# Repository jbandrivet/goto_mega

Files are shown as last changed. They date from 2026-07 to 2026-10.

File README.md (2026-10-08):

# GotoAndrivet — Contrôleur Multi-Montures OnStep

Ce projet supporte de manière universelle trois types de montures astronomiques :
1. **Alt-Azimutale (AltAz)** : Pour montures Dobson et Alt-Azimutales standards.
2. **Fourche Équatoriale (ForkEq)** : Pour montures équatoriales à fourche ou tables équatoriales (aucun retournement de méridien requis, suivi sidéral direct sur l'angle horaire).
3. **Monture Équatoriale Allemande (GermanEq / GEM)** : Pour montures équatoriales allemandes (gestion automatique du **retournement de méridien** et de la position de pilier *Pier Side* Est/Ouest).

---

## Structure du Projet

* **`goto_andrivet.py`** : L'application principale en Python (interface graphique Tkinter avec carte du ciel interactive, catalogues Messier/NGC/IC/Caldwell et dérotateur).
* **`goto_andrivet_config_tool.py`** : L'utilitaire de configuration en style Windows 95 permettant de régler les coordonnées, vitesses, rapports d'engrenage et de flasher le firmware.
* **`raquette_virtuelle.py`** : L'émulateur de la raquette Teensy pour piloter le télescope depuis l'ordinateur.
* **`mega_monture/`** : Le firmware classique (1 étoile) pour le contrôleur Arduino Mega 2560.
* **`teensy_monture/`** : Le nouveau firmware haute performance pour contrôleur Teensy 4.1 (Inclut le Modèle de Pointage N-Étoiles par interpolation IDW).
* **`teensy_raquette/`** : Le firmware C++ pour la raquette physique avec écran LCD (sur Teensy 4.1).

---

## Guide d'Installation & Mode d'Emploi

### 1. Prérequis
Pour exécuter les applications graphiques en Python sur votre ordinateur, vous devez disposer de **Python 3**, du module **Tkinter** et de la bibliothèque **pyserial**.

Sur Ubuntu / Debian / Raspberry Pi OS, installez-les via votre terminal :
```bash
sudo apt update
sudo apt install python3 python3-tk python3-pip
pip3 install pyserial
```

### 2. Démarrage des Applications
Exécutez les scripts Python correspondants depuis le dossier du projet :

* **Configuration & Flashage** :
  ```bash
  python3 goto_andrivet_config_tool.py
  ```
* **Cartographie du Ciel & Pilotage** :
  ```bash
  python3 goto_andrivet.py
  ```
* **Raquette Virtuelle (Émulateur)** :
  ```bash
  python3 raquette_virtuelle.py
  ```

### 3. Compiler & Flasher sans IDE Arduino
Vous pouvez programmer vos cartes directement depuis l'utilitaire de configuration (sans avoir besoin d'ouvrir l'IDE Arduino classique) :
1. Installez l'utilitaire [arduino-cli](https://arduino.github.io/arduino-cli/latest/) sur votre PC.
2. Ouvrez l'utilitaire de configuration (`python3 goto_andrivet_config_tool.py`).
3. Sélectionnez le **Port** série de votre carte dans les paramètres de connexion.
4. Dans l'encadré **« Téléversement du Firmware »**, cliquez sur le bouton correspondant à votre carte pour compiler et flasher automatiquement.

### 4. Schéma de Câblage Rapide (Monture : Mega ou Teensy)

Câblez votre contrôleur principal en suivant ce schéma (les broches sont identiques pour le Mega et le Teensy, à l'exception de la broche du Buzzer) :

| Composant / Axe | Broche Arduino Mega 2560 | Broche Teensy 4.1 | Signal Module / Driver |
| :--- | :--- | :--- | :--- |
| **Moteur Azimut (AZ/RA)** | **Pin 2** | **Pin 2** | `PUL+` (Pulse/Step) |
| | **Pin 3** | **Pin 3** | `DIR+` (Direction) |
| | **Pin 4** | **Pin 4** | `ENB+` (Enable) |
| **Moteur Altitude (ALT/DEC)** | **Pin 5** | **Pin 5** | `PUL+` (Pulse/Step) |
| | **Pin 6** | **Pin 6** | `DIR+` (Direction) |
| | **Pin 7** | **Pin 7** | `ENB+` (Enable) |
| **Moteur Dérotateur** | **Pin 8** | **Pin 8** | `PUL+` (Pulse/Step) |
| | **Pin 9** | **Pin 9** | `DIR+` (Direction) |
| | **Pin 10** | **Pin 10** | `ENB+` (Enable) |
| **Moteur Focuseur** | **Pin 11** | **Pin 11** | `PUL+` (Pulse/Step) |
| | **Pin 12** | **Pin 12** | `DIR+` (Direction) |
| | **Pin 13** | **Pin 21** | `ENB+` (Enable) |
| **Buzzer** | **Pin 49** | **Pin 20** | Borne `+` (actif : direct / passif : via résistance 100 Ω) |
| **Port Série PC** | **Non dispo** | **Pin 25 (RX6)** | `TX` de l'adaptateur USB/Série TTL (Câble long) |
| | **Non dispo** | **Pin 24 (TX6)** | `RX` de l'adaptateur USB/Série TTL |
| **Raquette Teensy** | **Pin 15 (RX3)** | **Pin 15 (RX3)** | `TX` de la raquette Teensy |
| | **Pin 14 (TX3)** | **Pin 14 (TX3)** | `RX` de la raquette Teensy |
| **Module GPS** | **Pin 17 (RX2)** | **Pin 17 (RX4)** | `TX` du module GPS |
| | **Pin 16 (TX2)** | **Pin 16 (TX4)** | `RX` du module GPS |

*Note : Les signaux de masse négatifs (`PUL-`, `DIR-`, `ENB-` des drivers, GND du buzzer, du GPS et de la Teensy) doivent tous être connectés à une broche **GND** de votre carte.*
*(Consultez le fichier `fiche_technique.md` pour des explications approfondies).*

### 4.1 Schéma de Câblage de la Raquette (Teensy 4.1)

Si vous fabriquez la raquette physique avec un Teensy 4.1, voici le câblage à effectuer :

| Composant | Broche Teensy 4.1 | Connexion / Signal |
| :--- | :--- | :--- |
| **Écran LCD (I2C)** | **Pin 18 (SDA0)** | `SDA` de l'écran LCD |
| | **Pin 19 (SCL0)** | `SCL` de l'écran LCD |
| | **VIN** | `VCC` (5V) de l'écran LCD |
| | **GND** | `GND` de l'écran LCD |
| **Boutons Poussoirs** | **Pin 6** | Bouton **Haut (UP)** (vers GND) |
| | **Pin 7** | Bouton **Bas (DOWN)** (vers GND) |
| | **Pin 8** | Bouton **Gauche (LEFT)** (vers GND) |
| | **Pin 9** | Bouton **Droite (RIGHT)** (vers GND) |
| | **Pin 10** | Bouton **Validation (ENTER)** (vers GND) |
| **Câble RJ11 (vers Mega)**| **GND** | Pin 1 RJ11 (`GND` de la Monture) |
| | **VIN** | Pin 2 RJ11 (`VIN` / `5V` de la Monture) |
| | **Pin 1 (TX1)** | Pin 3 RJ11 (vers `RX3` Pin 15 Monture) |
| | **Pin 0 (RX1)** | Pin 4 RJ11 (vers `TX3` Pin 14 Monture) |

*ATTENTION : Le Teensy est alimenté par la pin 5V du Mega via VIN. Ne pas brancher l'USB du Teensy en même temps, sauf si le pad VUSB a été coupé au préalable.*

### 5. Arduino Mega 2560 vs Teensy 4.1 (Contrôleur de Monture)

Le projet vous permet de choisir le cerveau principal de la monture. Bien que le câblage soit quasiment identique, voici les différences pour vous aider à choisir :

| Caractéristique | Arduino Mega 2560 | Teensy 4.1 |
| :--- | :--- | :--- |
| **Vitesse de calcul** | 16 MHz (8-bit) | **600 MHz** (32-bit ARM) |
| **Précision (Maths)** | Flottants 32-bit lents | **Flottants 64-bit (double)** natifs ultra-rapides |
| **Microstepping & Vitesse max**| Limité (saturera à très haut microstepping) | **Parfait** (génère des impulsions à plus de 200kHz sans sourciller) |
| **Modèle de pointage** | Basique | **N-Étoiles** (50 points mémorisés avec calculs IDW) |
| **Evolutivité (Futur)** | Faible | **Très haute** (Port USB Host pour Manette/Gamepad) |
| **Coût** | ~15-20€ (Clones pas chers) | ~35-40€ |

**Recommandation** : Si vous utilisez de petits drivers (1/16 ou 1/32 de pas) et voulez un système économique, le **Mega 2560** fait parfaitement le travail. Si vous utilisez des drivers modernes (TMC2209, M542) à fort microstepping (1/128, 1/256), que vous voulez des déplacements GoTo ultra-rapides et silencieux, et le modèle de pointage multi-étoiles intégré, optez sans hésiter pour le **Teensy 4.1**.

### 6. Matériel Compatible

Pour monter votre système GotoAndrivet, les composants matériels suivants sont compatibles et recommandés :

* **Cartes de Contrôle** :
  * **Arduino Mega 2560** ou **Teensy 4.1** (au choix pour la carte principale de la monture).
  * **Teensy 4.1** (pour la raquette de commande physique - *Optionnelle*).
* **Drivers de Moteurs** :
  * Drivers standard acceptant des entrées `PUL/DIR` (Impulsion/Direction) comme les modèles **M542**, **DM542**, **TB6600**, **TMC2209**, etc.
* **Moteurs** :
  * Moteurs pas à pas bipolaires (ex. **NEMA 17** ou **NEMA 23** en 200 pas/tour).
* **Module GPS (Optionnel)** :
  * Module **Adafruit Ultimate GPS** (MTK3339) ou tout autre récepteur GPS délivrant des trames NMEA standards à 9600 bauds sur port série.
* **Afficheur Raquette** :
  * Écran **LCD 20x4** caractères équipé d'un adaptateur **I2C** (généralement à l'adresse `0x27`).
* **Boutons Raquette** :
  * 5 boutons poussoirs momentanés (Haut, Bas, Gauche, Droite, Validation).
* **Alerte Sonore** :
  * Un **Buzzer actif 5V** ou un **Buzzer passif**. (Si vous utilisez un buzzer actif, câblez-le directement ; si vous utilisez un buzzer passif, ajoutez une résistance de 100 Ω en série avec le signal).

*Note concernant la raquette physique : La construction de la raquette matérielle (carte Teensy, écran LCD et boutons) n'est **pas obligatoire**. Si vous utilisez la monture en mode "remote", ou que vous la pilotez exclusivement depuis un PC, un planétarium, ou un boîtier type ASIAIR, l'Arduino Mega suffit à lui seul pour tout gérer via la connexion USB.*

---

## Fonctionnalités Avancées

* **Modèle de Pointage N-Étoiles (Teensy Monture uniquement)** : Interpolation des erreurs de suivi et de pointage par IDW (Inverse Distance Weighting) jusqu'à 50 étoiles mémorisées. Support de la commande de remise à zéro `:CML#`.
* **Ajout du type de monture `GermanEq`** : Le firmware de l'Arduino Mega calcule automatiquement les inversions d'axes (Ascension Droite et Déclinaison) lors du franchissement du méridien.
* **Commande standard `:Gm#` implémentée** : Renvoie le *Pier Side* (`E#` pour l'Est, `W#` pour l'Ouest, `N#` pour les autres modes) requis pour les logiciels de guidage comme Ekos/INDI.
* **Commande standard `:D#` implémentée** : Permet l'interrogation dynamique du statut de pointage (Slewing), accélérant drastiquement le modèle de pointage automatique ZWO en évitant les pauses fixes.
* **Intégration complète dans les interfaces** : Le sélecteur de monture dans `goto_andrivet_config_tool.py`, `goto_andrivet.py` et la raquette physique Teensy supporte désormais les trois options distinctes (`AltAz`, `ForkEq`, `GermanEq`).

---

## Licence

Ce projet est sous licence **GNU GPL v3**. Consultez le fichier [LICENSE](LICENSE) pour plus de détails.

## Mise à jour Matérielle (PCB 36V / 12V + Drivers Externes)
- Ajout du support matériel et logiciel (SPI) pour les drivers Pololu 36v8 et StepSticks TMC5160 HV.
- La carte mère dispose désormais de connecteurs universels (StepSticks + sorties pour drivers externes 4 pins).
- Suppression du port USB Host redondant sur le Teensy 4.1 de la monture pour simplifier le soudage.
- Ajout d'une prise Jack 12V standard en parallèle du bornier d'alimentation 36V.
- Le configurateur PC intègre maintenant une case à cocher pour activer dynamiquement le SPI matériel pour les drivers haute puissance.

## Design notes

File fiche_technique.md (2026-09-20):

# FICHE TECHNIQUE : SYSTÈME DE COMMANDE GOTO-ANDRIVET
*Version 9.2 (Dual Architecture : Mega & Teensy) — Juin 2026*

Ce document regroupe les spécifications électriques, le schéma de câblage des drivers **M542**, les paramètres mécaniques et les protocoles de communication pour le système de commande motorisé GoTo universel (GotoAndrivet).

---

## 1. Choix de l'Architecture (Monture Mega vs Teensy)

Le projet **Goto-Andrivet** propose désormais deux versions différentes pour le "cerveau" de la monture (le contrôleur moteur principal). Le choix de la carte affecte directement la puissance de calcul pour le suivi et les modèles de pointage.

### Option A : Contrôleur Arduino Mega 2560 (Dossier `mega_monture`)
* **Processeur :** 8-bit AVR @ 16 MHz.
* **Avantage :** Matériel très standard, robuste et peu cher.
* **Inconvénient :** Puissance de calcul très limitée. Il effectue d'excellents suivis basiques (1 étoile), mais il est incapable de faire fonctionner des modèles de pointage complexes (multi-étoiles) sans perdre la fluidité des moteurs.

### Option B : Contrôleur Teensy 4.1 (Dossier `teensy_monture`)
* **Processeur :** 32-bit ARM Cortex-M7 @ 600 MHz avec coprocesseur mathématique (FPU).
* **Avantage :** Une puissance phénoménale. Il génère des pas moteurs d'une fluidité parfaite même à très haute vitesse et permet les calculs matriciels complexes requis pour l'alignement multi-étoiles sans aucune saccade.
* **Inconvénient :** Plus coûteux.

> [!NOTE]
> Quel que soit le contrôleur choisi pour la monture, la télécommande (**Raquette**) reste toujours propulsée par un Teensy 4.1 (Dossier `teensy_raquette`) en raison de l'affichage graphique LCD et des calculs d'éphémérides requis.

---

## 2. Caractéristiques de Communication

*   **Liaison USB (PC / ASIAir / INDI) :** **38 400 bauds** (Vitesse optimisée pour la télémétrie en temps réel).
*   **Liaison Série PC (Connecteur PCB 4 broches / Serial6) :** **38 400 bauds** (Idéal pour câbles très longs avec adaptateur TTL/RS485).
*   **Liaison Raquette (Connecteur DIN 4 broches / Serial3) :** **38 400 bauds**.
*   **Protocole :** Meade LX200 avec extensions OnStep (supporté par KStars/Ekos, Stellarium, SkySafari).

---

## 3. Schéma de Câblage Électrique (Côté Monture)

Le câblage des drivers moteurs vers le contrôleur reste quasiment identique quelle que soit la carte utilisée. Les drivers M542 sont raccordés en configuration **Cathode Commune (GND commun)**.

### Broches selon le contrôleur choisi :

| Composant | Broche Arduino Mega 2560 | Broche Teensy 4.1 |
|---|---|---|
| **Moteur AZ (Step)** | Pin 2 | Pin 2 |
| **Moteur AZ (Dir)** | Pin 3 | Pin 3 |
| **Moteur ALT (Step)** | Pin 5 | Pin 5 |
| **Moteur ALT (Dir)** | Pin 6 | Pin 6 |
| **Buzzer (Actif ou Passif)** | Pin 49 | Pin 20 |
| **GPS (RX / TX)** | Pin 17 / Pin 16 (Serial2) | Pin 16 / Pin 17 (Serial4) |
| **Raquette (RX / TX)** | Pin 15 / Pin 14 (Serial3) | Pin 15 / Pin 14 (Serial3) |

> [!IMPORTANT]
> Pour le Teensy 4.1, les broches physiques pour le GPS restent aux emplacements 16 et 17, mais elles correspondent au port matériel `Serial4` (au lieu du `Serial2` sur le Mega). Le câblage physique des fils volants est donc préservé !

---

## 4. Paramètres Mécaniques et Résolutions

La résolution de déplacement (PPD - Pas par Degré) de la monture est calculée selon la formule :

$$PPD = \frac{\text{Pas Moteur} \times \text{Microstepping} \times \text{Rapport Réduction}}{360}$$

### Valeurs (À configurer par l'utilisateur) :
*   **Pas moteur par tour :** Généralement 200 pas (pour des moteurs 1.8°).
*   **Microstepping :** À configurer selon votre driver (ex: 16, 32, 64, 128).
*   **Rapport de réduction (AZ/ALT) :** Défini par l'utilisateur (à configurer impérativement via l'utilitaire selon votre mécanique propre).
*   **Résolution calculée (PPD) :** Calculée automatiquement par l'utilitaire en fonction des trois valeurs ci-dessus.

---

## 5. Modes de Suivi (Tracking)

*   **Suivi Sidéral (Ciel profond) :** Calculé en temps réel toutes les 500 ms à partir du Temps Sidéral Local (LST) de l'horloge.
*   **Suivi Lunaire (`:TL#`) :** Vitesse de l'angle horaire (HA) ralentie de **~2,37%** (facteur d'échelle `0.976327`) pour compenser le déplacement orbital de la Lune.
*   **Suivi Solaire (`:TS#`) :** Vitesse ralentie de **~0,27%** (facteur d'échelle `0.997270`) pour compenser le mouvement orbital de la Terre.

---

## 6. Câblage de la Raquette Physique (Teensy 4.1)

La raquette physique est articulée autour d'une carte **Teensy 4.1**.

### 1. Connecteur DIN 4 broches (Communication + Alimentation depuis la Monture)

| Pin DIN | Signal | Broche Teensy |
|---|---|---|
| **1** | GND | **GND** |
| **2** | 5V (alimentation) | **VIN** |
| **3** | TX (Teensy → Monture) | **Pin 1 (TX1)** |
| **4** | RX (Monture → Teensy) | **Pin 0 (RX1)** |

> [!WARNING]
> La monture doit fournir assez de courant au Teensy via la pin VIN. Ne pas alimenter le Teensy par son port USB si le câble DIN l'alimente déjà, sauf si le pad `VUSB` sous le Teensy a été physiquement sectionné.

### 2. Écran LCD Grove I2C
* **SDA** $\rightarrow$ Broche **Pin 18 (SDA0)** de la Teensy
* **SCL** $\rightarrow$ Broche **Pin 19 (SCL0)** de la Teensy
* **VCC** $\rightarrow$ Broche **5V** (ou **3.3V** selon le modèle Grove)
* **GND** $\rightarrow$ Broche **GND**

### 3. Boutons Poussoirs (Clavier directionnel)
Les boutons sont câblés en **INPUT_PULLUP** (reliés entre la broche et le GND). Aucun besoin de résistance externe !

* **Haut (UP)** $\rightarrow$ Broche **Pin 6**
* **Bas (DOWN)** $\rightarrow$ Broche **Pin 7**
* **Gauche (LEFT)** $\rightarrow$ Broche **Pin 8**
* **Droite (RIGHT)** $\rightarrow$ Broche **Pin 9**
* **Entrée/OK (ENTER)** $\rightarrow$ Broche **Pin 10**

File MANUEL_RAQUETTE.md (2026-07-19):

# Mode d'emploi : Raquette Teensy

Ce document décrit comment naviguer dans l'interface LCD de la raquette Teensy et détaille l'ensemble des menus disponibles.

## Navigation Générale

L'écran d'accueil affiche les coordonnées de la monture (soit en RA/DEC, soit en ALT/AZ). 

Depuis cet écran d'accueil :
- **Touches directionnelles (Haut, Bas, Gauche, Droite)** : Déplacement manuel des moteurs (vitesse de rattrapage).
- **Touche `ENTRÉE` (ou bouton central)** : Ouvre le Menu Principal.

À l'intérieur des menus :
- **Haut / Bas** : Déplacer le curseur de sélection ou modifier une valeur (par exemple changer un chiffre).
- **Entrée (ou Droite)** : Valider un choix ou entrer dans un sous-menu.
- **Gauche** : Annuler, reculer ou retourner au menu précédent.

## Le Menu Principal

En appuyant sur `Entrée` depuis l'écran d'accueil, vous accédez aux 15 options suivantes :

### 1. Catalogues
Permet d'accéder aux catalogues d'objets célestes (Messier, NGC, IC, Système Solaire, Étoiles remarquables). Sélectionnez un catalogue, puis un objet, et faites Entrée pour lancer le **GoTo** automatique vers cet objet.

### 2. Pause Moteurs / Reprendre Suivi
- **Pause Moteurs** : Coupe le suivi et l'alimentation des moteurs (pratique pour économiser la batterie ou manipuler la monture sans forcer). Le télescope retient sa position interne en fonction du temps qui passe.
- **Reprendre Suivi** : Réactive le suivi. Si vous aviez une cible GoTo active, le télescope va recalculer la position actuelle de la cible et s'y recentrer automatiquement.

### 3. Vitesse GoTo
Permet de brider la vitesse maximale des moteurs lors des grands déplacements (GoTo). Utile si votre alimentation est faible ou pour réduire le bruit (en degrés par seconde).

### 4. Buzzer
Active ou désactive les bips de confirmation de la raquette.

### 5. Synchroniser
Procédure d'alignement. Après avoir lancé un GoTo vers une étoile ou une planète, centrez-la parfaitement à l'aide des touches fléchées puis utilisez cette fonction. L'Arduino va alors se "synchroniser" et considérer que sa position mécanique actuelle correspond exactement à cet objet.

### 6. Parking
Gère la mise au repos de la monture.
- **Parquer** : Envoie le télescope vers sa position de repos sécurisée et coupe le suivi.
- **Déparquer** : Réveille la monture pour une nouvelle session (sans perdre l'alignement).
- **Définir Position** : Enregistre la position *actuelle* comme étant la future position de parking.

### 7. Type Monture
Définit la géométrie de votre monture :
- Alt-Az (Azimutale)
- Equatorial (Fourche ou Allemande)

### 8. Ratio AZ / Ratio RA
Règle la démultiplication mécanique (ratio des poulies/engrenages) de l'axe Azimut (ou Ascension Droite).

### 9. Ratio ALT / Ratio DEC
Règle la démultiplication mécanique de l'axe Altitude (ou Déclinaison).

### 10. Alim Moteurs
Permet d'allumer ou d'éteindre complètement l'étage de puissance des moteurs manuellement.

### 11. Date / Heure
Règle la date et l'heure locale, ainsi que le décalage UTC. *(L'heure est essentielle pour le calcul des positions célestes).*

### 12. Lieu Obs.
Saisie des coordonnées GPS de votre lieu d'observation (Latitude et Longitude).

### 13. Langue
Bascule l'interface de la raquette entre le **Français** et l'**Anglais**.

### 14. GPS Auto
Active ou désactive la synchronisation automatique de l'heure et du lieu grâce au module GPS matériel (si branché).

### 15. Affichage Coord
Permet de choisir ce que l'écran d'accueil affiche en temps réel :
- Coordonnées équatoriales (Ascension Droite et Déclinaison).
- Coordonnées horizontales (Altitude et Azimut).

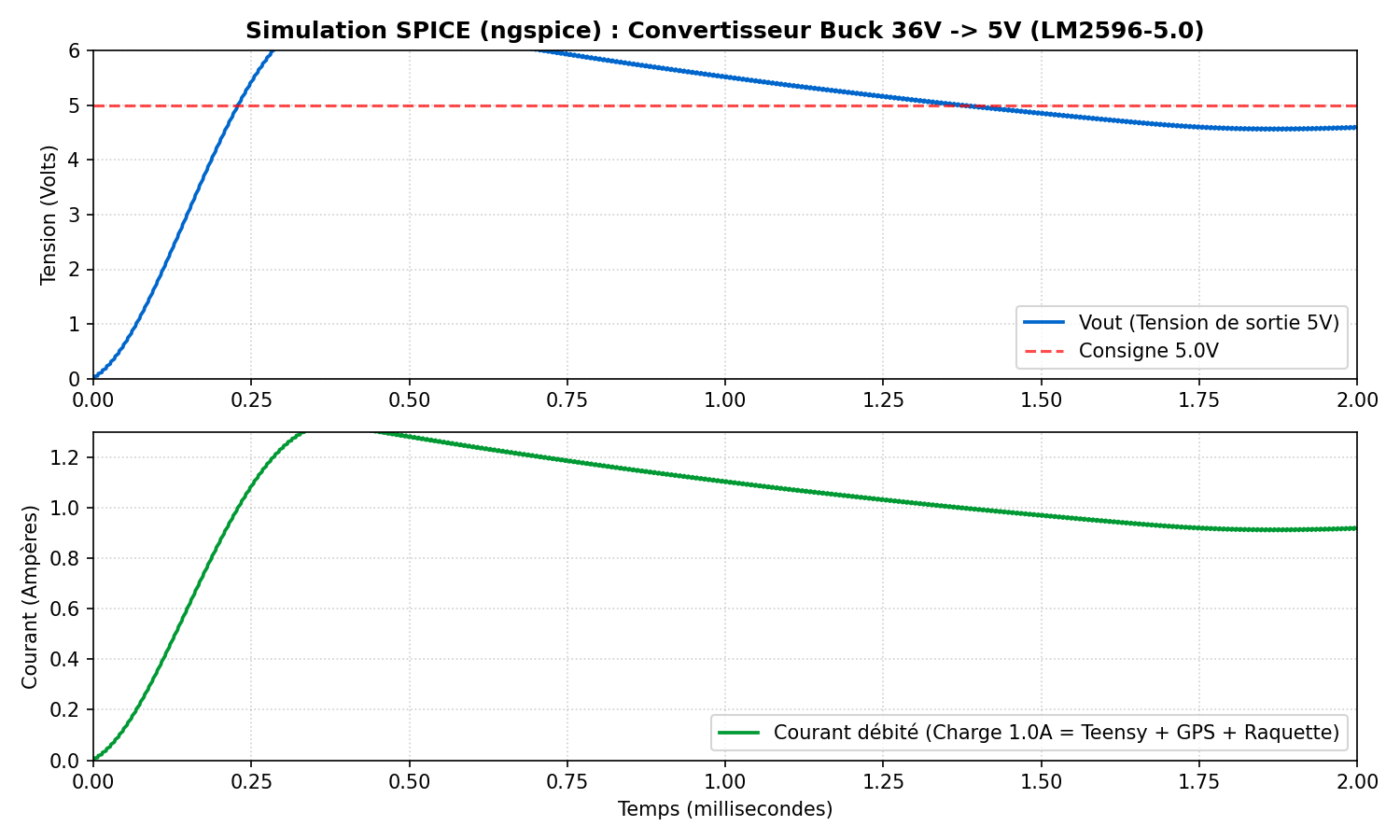
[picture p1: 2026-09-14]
pcb/simulation/simulation_buck_36v_5v.png

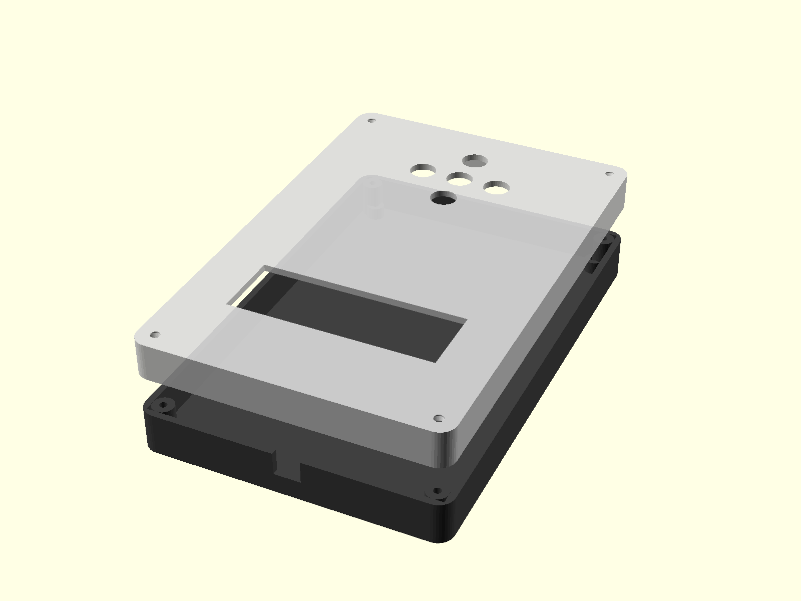
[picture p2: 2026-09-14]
pcb/raquette/boitier_raquette_3d.png

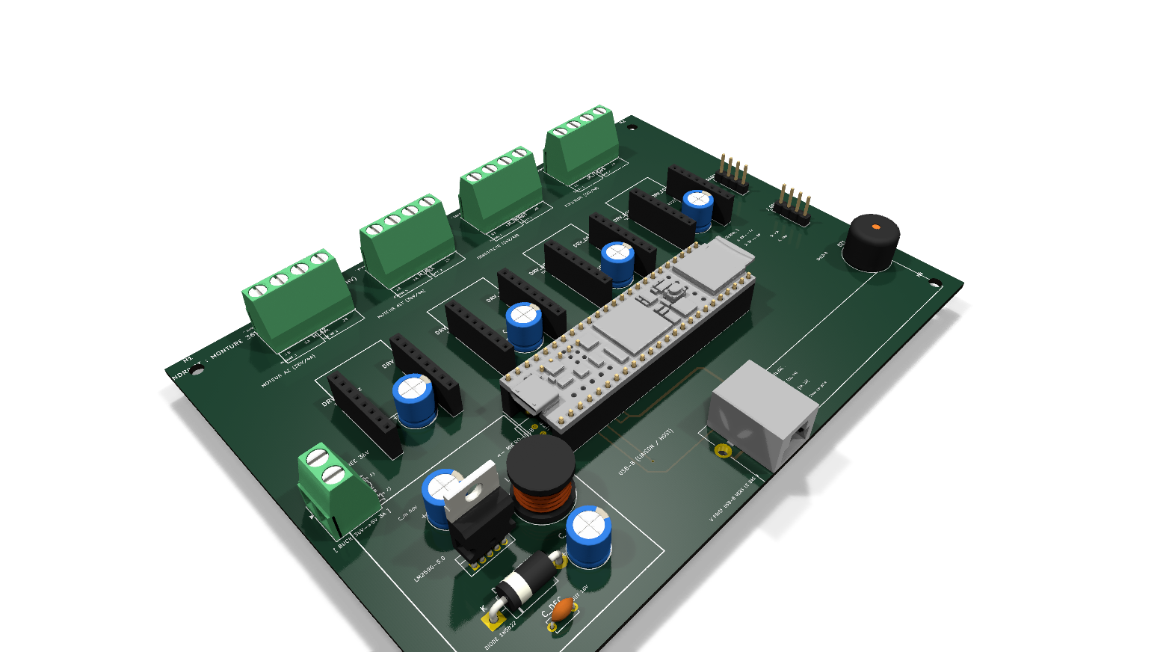
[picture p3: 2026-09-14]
pcb/monture/monture_3d.png

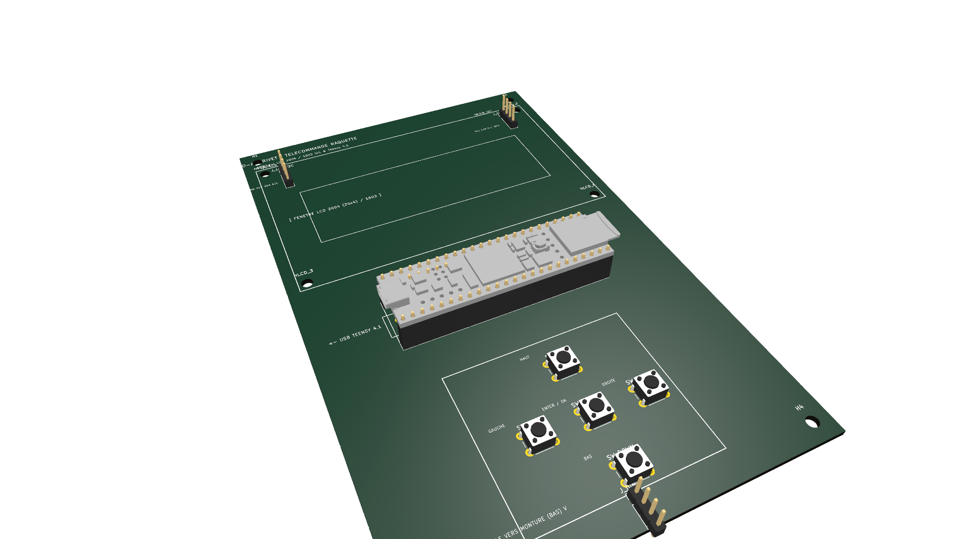
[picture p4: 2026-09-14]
pcb/raquette/raquette_3d.png

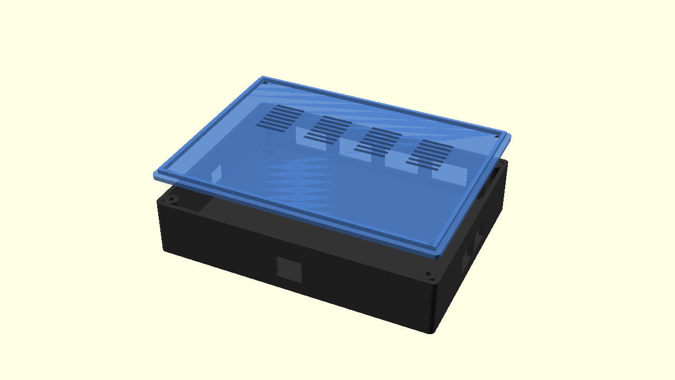
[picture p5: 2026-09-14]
pcb/monture/boitier_monture_3d.png

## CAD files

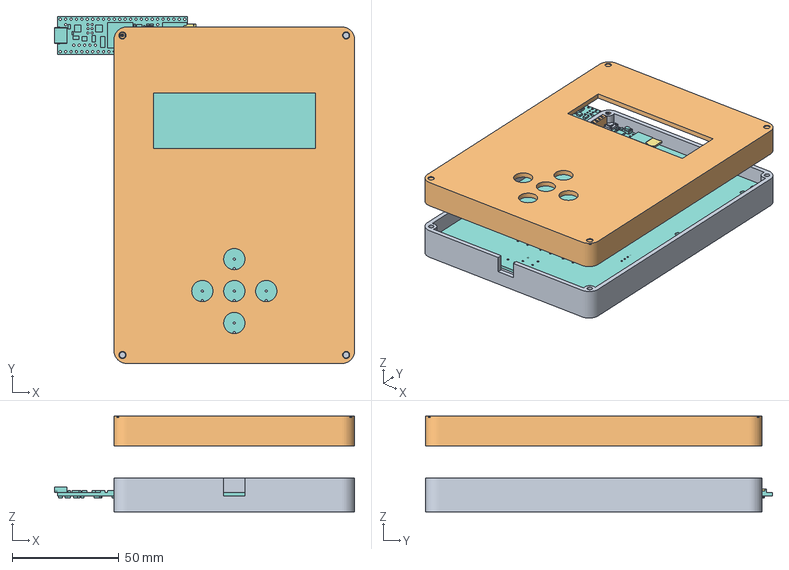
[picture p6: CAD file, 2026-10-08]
pcb/raquette/boitier_raquette_assemblage.FCStd
141.0 x 162.9 x 45.0 mm
PinSocket_1x24_P2.54mm_Vertical
PinSocket_1x24_P2.54mm_Vertical002
PinHeader_1x24_P254mm_Vertical
PinHeader_1x24_P254mm_Vertical001
PinSocket_1x05_P2.54mm_Vertical
PinHeader_1x05_P254mm_Vertical
Teensy_4.1_Assembly_R1
Teensy_4.1_Assembly_R001
SW_PUSH_6mm
SW_PUSH_6mm002
SW_PUSH_6mm004
PinHeader_1x04_P254mm_Vertical
SW_PUSH_6mm006
SW_PUSH_6mm008
PinHeader_1x04_P254mm_Vertical001
raquette_PCB
Boitier_Raquette_Base
Boitier_Raquette_Face_Avant

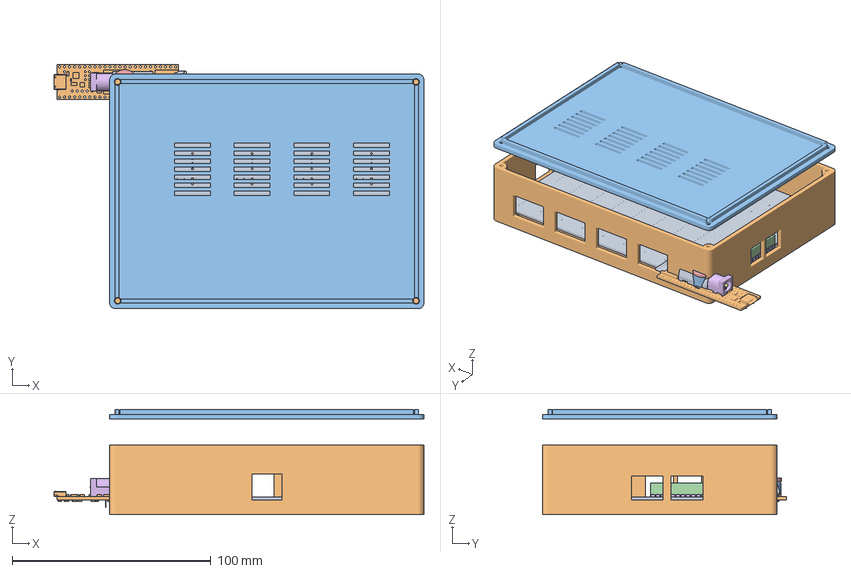
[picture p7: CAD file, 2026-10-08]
pcb/monture/boitier_monture_assemblage.FCStd
186.0 x 122.9 x 53.0 mm
PinHeader_1x04_P254mm_Vertical
D_DO-201AD_P15.24mm_Horizontal
PinSocket_1x08_P2.54mm_Vertical
CP_Radial_D80mm_P350mm
PinHeader_1x04_P254mm_Vertical001
PinSocket_1x08_P2.54mm_Vertical002
CP_Radial_D80mm_P350mm001
TerminalBlock_Phoenix_MKDS_15_4_508_1x04_P508mm_Horizontal
PinSocket_1x08_P2.54mm_Vertical004
C_Disc_D50mm_W25mm_P500mm
TerminalBlock_Phoenix_MKDS_15_4_508_1x04_P508mm_Horizontal001
PinSocket_1x08_P2.54mm_Vertical006
CP_Radial_D80mm_P350mm002
CP_Radial_D80mm_P350mm003
PinSocket_1x08_P2.54mm_Vertical008
PinSocket_1x08_P2.54mm_Vertical010
TerminalBlock_Phoenix_MKDS_15_4_508_1x04_P508mm_Horizontal002
TerminalBlock_Phoenix_MKDS_15_4_508_1x04_P508mm_Horizontal003
PinHeader_1x04_P254mm_Vertical002
CP_Radial_D80mm_P350mm004
TerminalBlock_Phoenix_MKDS_15_2_508_1x02_P508mm_Horizontal
BarrelJack_Horizontal
BarrelJack_Horizontal001
BarrelJack_Horizontal002
BarrelJack_Horizontal003
BarrelJack_Horizontal004
PinSocket_1x24_P2.54mm_Vertical
PinSocket_1x24_P2.54mm_Vertical002
PinHeader_1x24_P254mm_Vertical
PinHeader_1x24_P254mm_Vertical001
PinSocket_1x05_P2.54mm_Vertical
PinHeader_1x05_P254mm_Vertical
Teensy_4.1_Assembly_R1
Teensy_4.1_Assembly_R001
Buzzer_12x95RM76
PinSocket_1x08_P2.54mm_Vertical012
L_Radial_D12.5mm_P7.00mm_Fastron_09HCP
TO_220_5_Pentawatt_Multiwatt_5_Vertical
PinSocket_1x08_P2.54mm_Vertical014
CP_Radial_D80mm_P350mm005
monture_PCB
boitier_monture_base
boitier_monture_couvercle

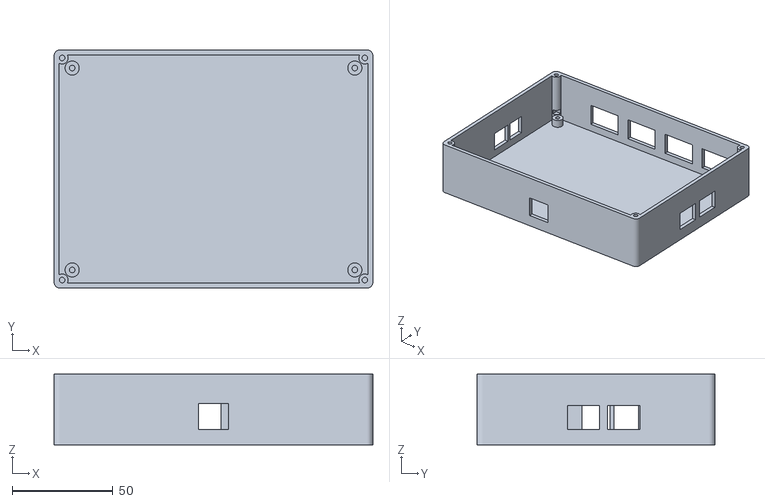
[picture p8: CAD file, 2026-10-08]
pcb/monture/boitier_monture_base.stl
158.0 x 118.0 x 35.0

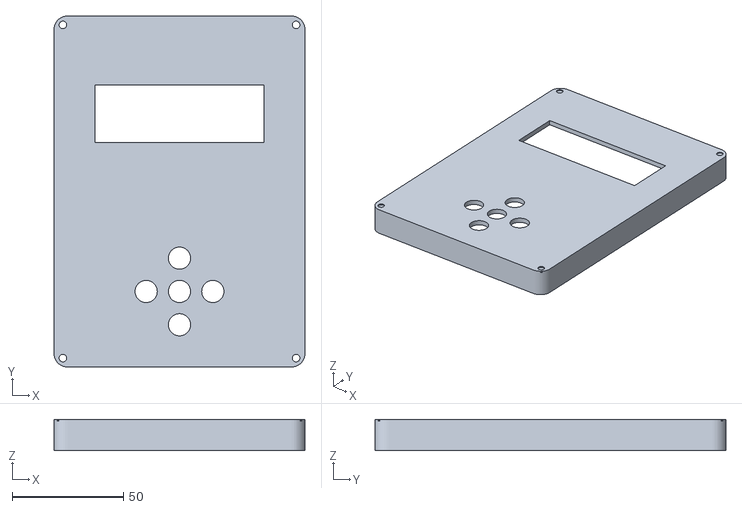
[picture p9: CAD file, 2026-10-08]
pcb/raquette/boitier_raquette_face_avant.stl
113.0 x 158.0 x 14.0

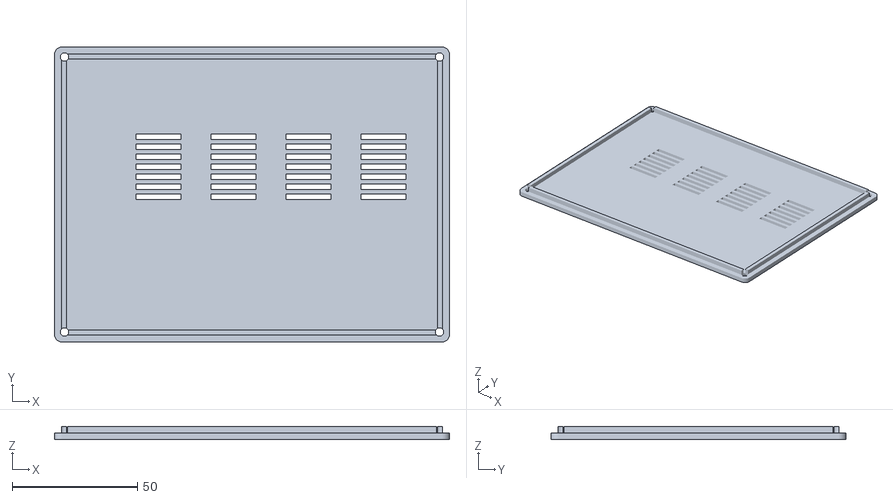
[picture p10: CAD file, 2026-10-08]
pcb/monture/boitier_monture_couvercle.stl
158.0 x 118.0 x 5.00

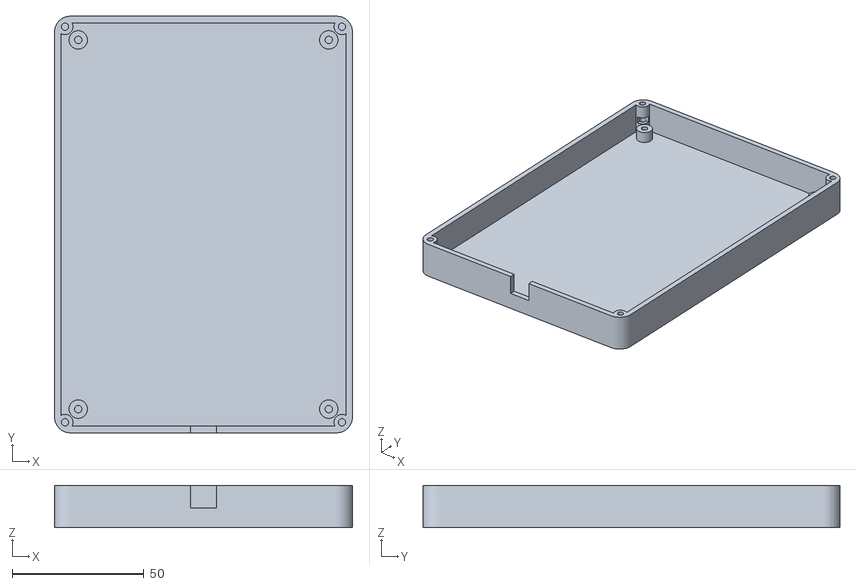
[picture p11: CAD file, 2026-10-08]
pcb/raquette/boitier_raquette_base.stl
113.0 x 158.0 x 16.0

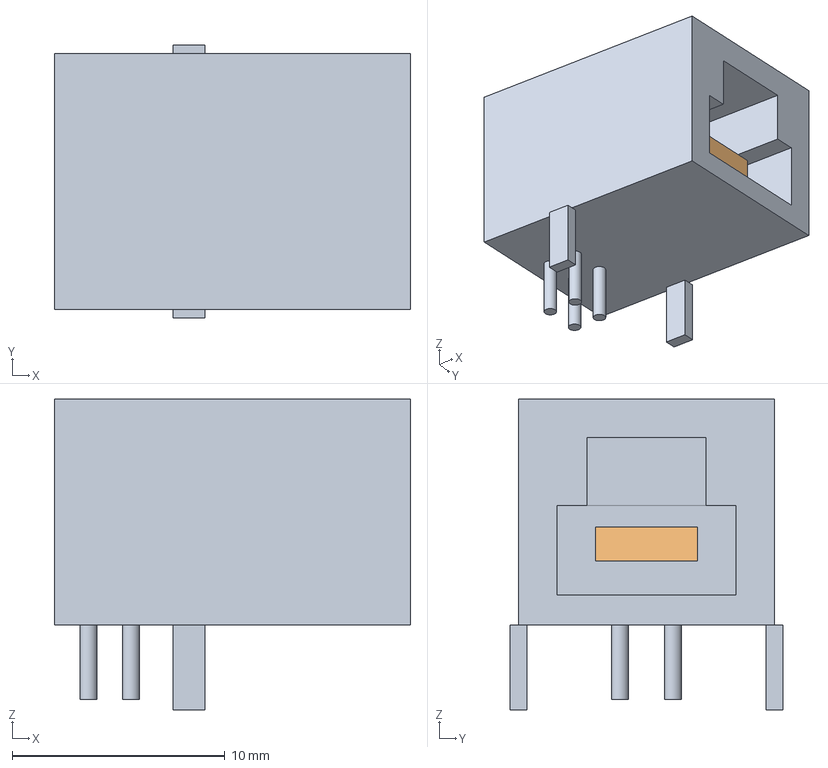
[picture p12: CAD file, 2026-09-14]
pcb/monture/USB_B_OST_USB-B1HSxx_Horizontal.step
16.7 x 12.8 x 14.6 mm

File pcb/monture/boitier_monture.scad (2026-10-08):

// ============================================================================
// BOITIER PARAMÉTRIQUE POUR MONTURE GOTO-ANDRIVET (36V / 4A)
// Conçu pour impression 3D (PLA / PETG / ABS)
// ============================================================================

$fn = 40;

// Dimensions du PCB
pcb_w = 150;
pcb_h = 110;
pcb_thick = 1.6;

// Paramètres du boîtier
wall = 2.5;         // Épaisseur des parois
clearance = 1.5;    // Jeu autour du PCB
standoff_h = 5.0;   // Hauteur des entretoises sous le PCB
box_h = 35.0;       // Hauteur totale interne du boîtier (35mm pour dégager le TO-220 LM2596)
lid_thick = 2.5;    // Épaisseur du couvercle

inner_w = pcb_w + 2 * clearance;
inner_h = pcb_h + 2 * clearance;
outer_w = inner_w + 2 * wall;
outer_h = inner_h + 2 * wall;

// Positions des 4 trous de fixation PCB M3 (relatifs au coin inférieur gauche interne)
pcb_holes = [
    [clearance + 5, clearance + 5],
    [clearance + pcb_w - 5, clearance + 5],
    [clearance + 5, clearance + pcb_h - 5],
    [clearance + pcb_w - 5, clearance + pcb_h - 5]
];

// ----------------------------------------------------------------------------
// 1. CORPS INFÉRIEUR (BASE DU BOÎTIER)
// ----------------------------------------------------------------------------
module boitier_base() {
    difference() {
        union() {
            difference() {
        // Volume extérieur avec coins arrondis
        hull() {
            translate([3, 3, 0]) cylinder(r=3, h=box_h);
            translate([outer_w - 3, 3, 0]) cylinder(r=3, h=box_h);
            translate([3, outer_h - 3, 0]) cylinder(r=3, h=box_h);
            translate([outer_w - 3, outer_h - 3, 0]) cylinder(r=3, h=box_h);
        }

        // Évidement intérieur
        translate([wall, wall, wall])
            cube([inner_w, inner_h, box_h + 1]);

        // --- DÉCOUPES DE PASSAGE DES CONNECTEURS EXTÉRIEURS (PARFAITEMENT CENTRÉES SUR LE PCB) ---

        // A. 4 Ouvertures Moteurs sur le bord haut (Y = max, centrés exactement sur les connecteurs M_AZ, M_ALT, M_DEROT, M_FOCUS)
        motor_x = [37.62, 67.62, 97.62, 127.62];
        for (mx = motor_x) {
            translate([wall + clearance + mx - 11, outer_h - wall - 1, wall + standoff_h])
                cube([22, wall + 2, 14]);
        }

        // B. Bord bas (Y = 0) : Connecteur USB-B Femelle (Parfaitement centré à X = 75.0mm)
        translate([wall + clearance + 75.0 - 7.5, -1, wall + standoff_h])
            cube([15.0, wall + 2, 13.0]);

        // C. Flanc gauche (X = 0) : Entrée 36V et Sortie auxiliaire 12V
        // Entrée 36V (Y_kicad = 55.0mm -> Y_scad = 55.0mm)
        translate([-1, wall + clearance + 55.0 - 7, wall + standoff_h])
            cube([wall + 2, 14, 12]);
        // Sortie auxiliaire 12V (Y_kicad = 40.0mm -> Y_scad = 110 - 40 = 70.0mm)
        translate([-1, wall + clearance + 70.0 - 6, wall + standoff_h])
            cube([wall + 2, 12, 12]);

        // D. Flanc droit (X = max) : Raquette DIN et GPS (Parfaitement alignés sur les connecteurs du PCB)
        // Connecteur Raquette (Y_kicad = 41.19mm -> Y_scad = 110 - 41.19 = 68.81mm)
        translate([outer_w - wall - 1, wall + clearance + 68.81 - 8, wall + standoff_h])
            cube([wall + 2, 16, 12]);
        // Connecteur GPS (Y_kicad = 61.19mm -> Y_scad = 110 - 61.19 = 48.81mm)
        translate([outer_w - wall - 1, wall + clearance + 48.81 - 8, wall + standoff_h])
            cube([wall + 2, 16, 12]);

        // E. Trous de vis de fixation du couvercle dans les 4 coins
        corners = [
        [wall + 1.5, wall + 1.5],
        [outer_w - wall - 1.5, wall + 1.5],
        [wall + 1.5, outer_h - wall - 1.5],
        [outer_w - wall - 1.5, outer_h - wall - 1.5]
    ];
        for (c = corners) {
            translate([c[0], c[1], box_h - 12])
                cylinder(d=2.8, h=15); // Trou pour vis M3 taraudée
        }
    }

    // Piliers / Entretoises de support pour visser le PCB
    for (p = pcb_holes) {
        translate([wall + p[0], wall + p[1], wall - 0.2]) {
            difference() {
                cylinder(d=7.0, h=standoff_h + 0.2);
                translate([0, 0, -0.1])
                    cylinder(d=2.8, h=standoff_h + 1); // Trou vis PCB M3
            }
        }
    }

    // Renforts de coins pour les vis de fermeture du couvercle
    corners = [
        [wall + 1.5, wall + 1.5],
        [outer_w - wall - 1.5, wall + 1.5],
        [wall + 1.5, outer_h - wall - 1.5],
        [outer_w - wall - 1.5, outer_h - wall - 1.5]
    ];
    for (c = corners) {
        translate([c[0], c[1], wall - 0.2]) {
            difference() {
                cylinder(d=6.0, h=box_h - wall + 0.2);
                translate([0, 0, box_h - wall - 12])
                    cylinder(d=2.8, h=13);
            }
        }
    }
        }
        // Dégagement garanti des coins pour insertion du PCB
        translate([wall + clearance - 0.5, wall + clearance - 0.5, wall + standoff_h])
            cube([pcb_w + 1.0, pcb_h + 1.0, pcb_thick + 1.5]);
    }
}

// ----------------------------------------------------------------------------
// 2. COUVERCLE SUPÉRIEUR (AVEC GRILLE D'AÉRATION DES DRIVERS TMC5160)
// ----------------------------------------------------------------------------
module boitier_couvercle() {
    difference() {
        union() {
            // Plaque du couvercle
            hull() {
                translate([3, 3, 0]) cylinder(r=3, h=lid_thick);
                translate([outer_w - 3, 3, 0]) cylinder(r=3, h=lid_thick);
                translate([3, outer_h - 3, 0]) cylinder(r=3, h=lid_thick);
                translate([outer_w - 3, outer_h - 3, 0]) cylinder(r=3, h=lid_thick);
            }
            // Rebord d'emboîtement intérieur
            translate([wall + 0.3, wall + 0.3, lid_thick])
                difference() {
                    cube([inner_w - 0.6, inner_h - 0.6, 2.5]);
                    translate([2, 2, -0.5])
                        cube([inner_w - 4.6, inner_h - 4.6, 4]);
                }
        }

        // Trous de passage de vis M3 chanfreinés dans les 4 coins
        corners = [
        [wall + 1.5, wall + 1.5],
        [outer_w - wall - 1.5, wall + 1.5],
        [wall + 1.5, outer_h - wall - 1.5],
        [outer_w - wall - 1.5, outer_h - wall - 1.5]
    ];
        for (c = corners) {
            translate([c[0], c[1], -1]) {
                cylinder(d=3.4, h=lid_thick + 5);
                cylinder(d1=6.5, d2=3.4, h=2.5); // Fraisage tête de vis
            }
        }

        // Grilles d'aération au-dessus des 4 drivers TMC5160 pour dissipation thermique
        // Drivers centrés sur les TMC5160 : X = [37.62, 67.62, 97.62, 127.62], Y_kicad = 45mm -> Y_scad = 65mm
        for (cx = [37.62, 67.62, 97.62, 127.62]) {
            for (gy = [-12 : 4 : 12]) {
                translate([wall + clearance + cx - 9, wall + clearance + 65 + gy, -1])
                    cube([18, 2.2, lid_thick + 2]);
            }
        }
    }
}

// ----------------------------------------------------------------------------
// CHOIX DU MODELE A AFFICHER / RENDRE
// Passer 'mode' à "base", "couvercle", ou "ensemble"
// ----------------------------------------------------------------------------
mode = "ensemble";

if (mode == "base") {
    boitier_base();
} else if (mode == "couvercle") {
    boitier_couvercle();
} else {
    // Vue assemblée éclatée
    color([0.2, 0.2, 0.2]) boitier_base();
    color([0.3, 0.5, 0.8, 0.85])
        translate([0, 0, box_h + 15])
            boitier_couvercle();
}

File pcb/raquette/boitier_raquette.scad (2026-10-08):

// ============================================================================
// BOITIER ERGONOMIQUE POUR TÉLÉCOMMANDE RAQUETTE GOTO-ANDRIVET
// Conçu pour impression 3D (PLA / PETG / ABS)
// ============================================================================

$fn = 40;

// Dimensions du PCB
pcb_w = 105;
pcb_h = 150;

// Paramètres du boîtier
wall = 2.5;
clearance = 1.5;
standoff_h = 5.0;
base_h = 16.0;      // Hauteur coque arrière
top_h = 14.0;       // Hauteur face avant

inner_w = pcb_w + 2 * clearance;
inner_h = pcb_h + 2 * clearance;
outer_w = inner_w + 2 * wall;
outer_h = inner_h + 2 * wall;

// Centre X de la raquette
cx = outer_w / 2.0;

// ----------------------------------------------------------------------------
// 1. COQUE ARRIÈRE (BASE DU BOÎTIER)
// ----------------------------------------------------------------------------
module raquette_base() {
    difference() {
        union() {
            difference() {
        // Forme extérieure arrondie et ergonomique en main
        hull() {
            translate([6, 6, 0]) cylinder(r=6, h=base_h);
            translate([outer_w - 6, 6, 0]) cylinder(r=6, h=base_h);
            translate([6, outer_h - 6, 0]) cylinder(r=6, h=base_h);
            translate([outer_w - 6, outer_h - 6, 0]) cylinder(r=6, h=base_h);
        }

        // Cavité intérieure
        translate([wall, wall, wall])
            cube([inner_w, inner_h, base_h + 1]);

        // Encoche de passage du câble vers la monture en bas au centre
        translate([cx - 5, -1, wall + standoff_h])
            cube([10, wall + 2, 10]);

        // Trous filetés M3 dans les 4 coins pour la fermeture
        corners = [
        [wall + 1.5, wall + 1.5],
        [outer_w - wall - 1.5, wall + 1.5],
        [wall + 1.5, outer_h - wall - 1.5],
        [outer_w - wall - 1.5, outer_h - wall - 1.5]
    ];
        for (c = corners) {
            translate([c[0], c[1], base_h - 10])
                cylinder(d=2.8, h=12);
        }
    }

    // Piliers de fixation du PCB
    pcb_holes = [
        [clearance + 5, clearance + 5],
        [clearance + pcb_w - 5, clearance + 5],
        [clearance + 5, clearance + pcb_h - 5],
        [clearance + pcb_w - 5, clearance + pcb_h - 5]
    ];
    for (p = pcb_holes) {
        translate([wall + p[0], wall + p[1], wall]) {
            difference() {
                cylinder(d=7.0, h=standoff_h);
                cylinder(d=2.8, h=standoff_h + 1);
            }
        }
    }

    // Renforts des 4 coins
    corners = [
        [wall + 1.5, wall + 1.5],
        [outer_w - wall - 1.5, wall + 1.5],
        [wall + 1.5, outer_h - wall - 1.5],
        [outer_w - wall - 1.5, outer_h - wall - 1.5]
    ];
    for (c = corners) {
        translate([c[0], c[1], wall]) {
            difference() {
                cylinder(d=6.0, h=base_h - wall);
                translate([0, 0, base_h - wall - 10])
                    cylinder(d=2.8, h=11);
            }
        }
    }
        }
        // Dégagement garanti des coins pour insertion du PCB
        translate([wall + clearance - 0.5, wall + clearance - 0.5, wall + standoff_h])
            cube([pcb_w + 1.0, pcb_h + 1.0, 3.0]);
    }
}

// ----------------------------------------------------------------------------
// 2. FACE AVANT (FENÊTRE ÉCRAN LCD + OUVERTURES DES TOUCHES D-PAD)
// ----------------------------------------------------------------------------
module raquette_face_avant() {
    difference() {
        union() {
            // Façade avec bords arrondis
            hull() {
                translate([6, 6, 0]) cylinder(r=6, h=top_h);
                translate([outer_w - 6, 6, 0]) cylinder(r=6, h=top_h);
                translate([6, outer_h - 6, 0]) cylinder(r=6, h=top_h);
                translate([outer_w - 6, outer_h - 6, 0]) cylinder(r=6, h=top_h);
            }
        }

        // Évidement interne
        translate([wall, wall, -1])
            cube([inner_w, inner_h, top_h - wall + 1]);

        // A. Fenêtre de l'Écran LCD 2004 / 1602 avec chanfrein esthétique
        // Centrée à Y = 110 (puisque dans KiCad l'écran est à Y=40, et la carte fait 150)
        lcd_y = wall + clearance + 110;
        translate([cx - 38, lcd_y - 13, -1]) {
            cube([76, 26, top_h + 2]);
        }

        // B. 5 Trous circulaires pour les boutons du D-Pad (10 mm pour capuchons)
        // Centrés à Y = 30 (puisque dans KiCad ENTER est à Y=120, et la carte fait 150)
        btn_y = wall + clearance + 30;
        btn_spacing = 15;
        buttons = [
            [cx, btn_y + btn_spacing],              // HAUT (plus haut en Y)
            [cx - btn_spacing, btn_y],              // GAUCHE
            [cx, btn_y],                            // ENTER / OK
            [cx + btn_spacing, btn_y],              // DROITE
            [cx, btn_y - btn_spacing]               // BAS (plus bas en Y)
        ];
        for (b = buttons) {
            translate([b[0], b[1], -1])
                cylinder(d=10.0, h=top_h + 2);
        }

        // C. Trous de passage des 4 vis de fermeture M3 chanfreinées
        corners = [
        [wall + 1.5, wall + 1.5],
        [outer_w - wall - 1.5, wall + 1.5],
        [wall + 1.5, outer_h - wall - 1.5],
        [outer_w - wall - 1.5, outer_h - wall - 1.5]
    ];
        for (c = corners) {
            translate([c[0], c[1], -1]) {
                cylinder(d=3.4, h=top_h + 2);
                translate([0, 0, top_h - 2])
                    cylinder(d1=3.4, d2=6.5, h=2.5);
            }
        }
    }
}

// ----------------------------------------------------------------------------
// CHOIX DU MODELE
// ----------------------------------------------------------------------------
mode = "ensemble";

if (mode == "base") {
    raquette_base();
} else if (mode == "face_avant") {
    raquette_face_avant();
} else {
    color([0.25, 0.25, 0.25]) raquette_base();
    color([0.85, 0.85, 0.85, 0.9])
        translate([0, 0, base_h + 15])
            raquette_face_avant();
}

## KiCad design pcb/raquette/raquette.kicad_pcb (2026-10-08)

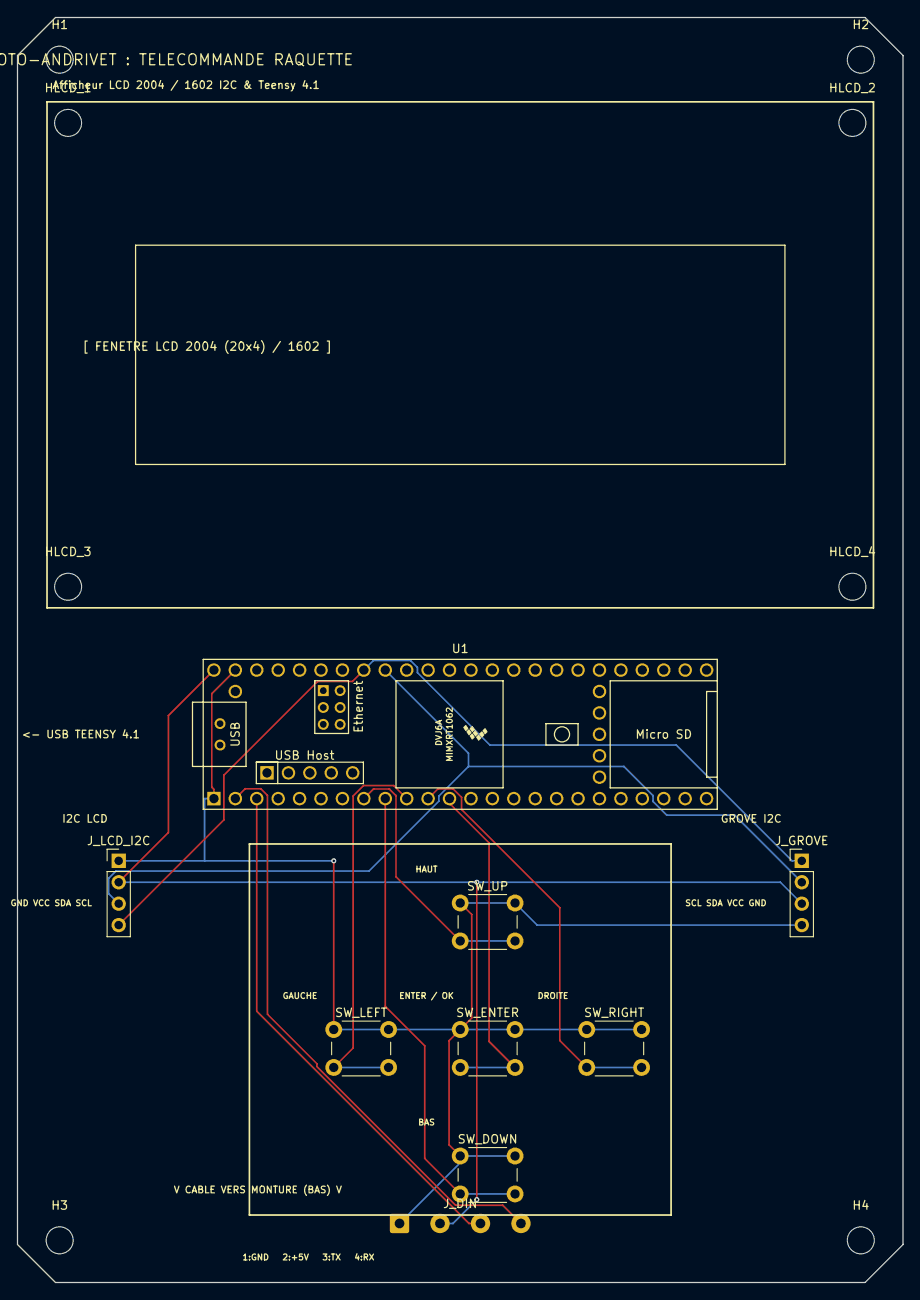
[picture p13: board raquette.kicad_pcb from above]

Board: 2 copper layers, 105.0 x 150.0 mm, 17 parts (0 on the bottom side), 11 nets.

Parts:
H1, H2, H3, H4: M3 Fixation; MountingHole_3.2mm_M3
HLCD_1, HLCD_2, HLCD_3, HLCD_4: M3 Entretoise LCD; MountingHole_3.2mm_M3
J_DIN: CABLE MONTURE; SolderWire-0.5sqmm_1x04_P4.8mm_D0.9mm_OD2.3mm
J_GROVE: Grove I2C Aux; PinHeader_1x04_P2.54mm_Vertical
J_LCD_I2C: LCD Backpack I2C; PinHeader_1x04_P2.54mm_Vertical
SW_DOWN: BAS; SW_PUSH_6mm
SW_ENTER: ENTER / OK; SW_PUSH_6mm
SW_LEFT: GAUCHE; SW_PUSH_6mm
SW_RIGHT: DROITE; SW_PUSH_6mm
SW_UP: HAUT; SW_PUSH_6mm
U1: Teensy 4.1; Teensy41

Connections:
+5V: J_DIN.2, J_GROVE.3, J_LCD_I2C.2, U1.48
BTN_DOWN: SW_DOWN.2, U1.9
BTN_ENTER: SW_ENTER.2, U1.12
BTN_LEFT: SW_LEFT.2, U1.10
BTN_RIGHT: SW_RIGHT.2, U1.11
BTN_UP: SW_UP.2, U1.8
GND: J_DIN.1, J_GROVE.4, J_LCD_I2C.1, SW_DOWN.1, SW_ENTER.1, SW_LEFT.1, SW_RIGHT.1, SW_UP.1, U1.1, U1.47
I2C_SCL: J_GROVE.1, J_LCD_I2C.4, U1.41
I2C_SDA: J_GROVE.2, J_LCD_I2C.3, U1.40
RAQ_RX: J_DIN.4, U1.2
RAQ_TX: J_DIN.3, U1.3

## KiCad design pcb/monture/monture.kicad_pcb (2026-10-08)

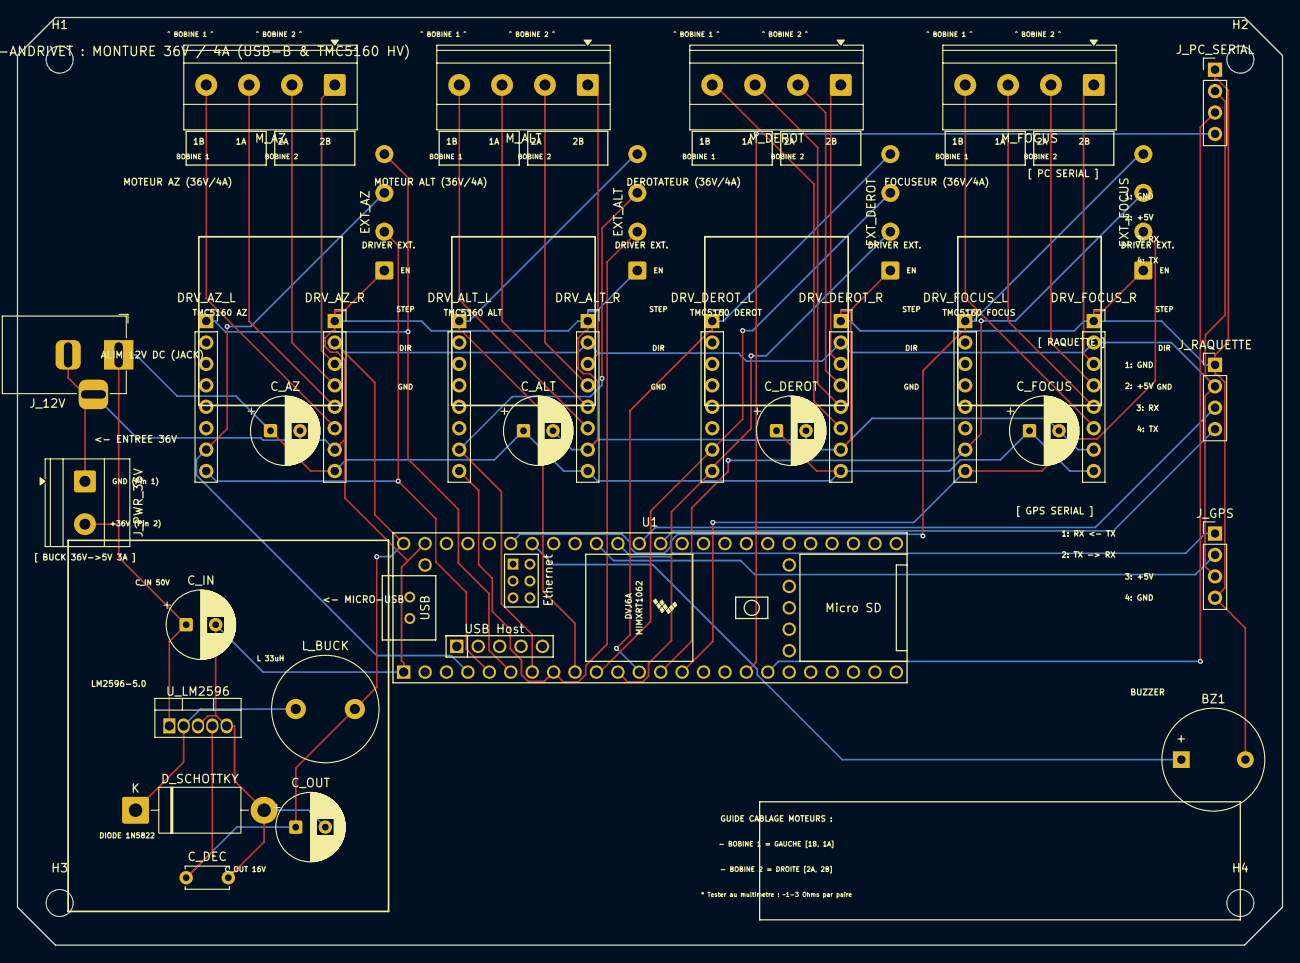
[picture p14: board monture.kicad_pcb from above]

Board: 2 copper layers, 150.0 x 110.0 mm, 37 parts (0 on the bottom side), 39 nets.

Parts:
BZ1: Buzzer; Buzzer_12x9.5RM7.6
C_ALT: 470uF 63V; CP_Radial_D8.0mm_P3.50mm
C_AZ: 470uF 63V; CP_Radial_D8.0mm_P3.50mm
C_DEC: 100nF; C_Disc_D5.0mm_W2.5mm_P5.00mm
C_DEROT: 470uF 63V; CP_Radial_D8.0mm_P3.50mm
C_FOCUS: 470uF 63V; CP_Radial_D8.0mm_P3.50mm
C_IN: 100uF 50V; CP_Radial_D8.0mm_P3.50mm
C_OUT: 220uF 16V; CP_Radial_D8.0mm_P3.50mm
DRV_ALT_L: Logique; PinSocket_1x08_P2.54mm_Vertical
DRV_ALT_R: Puissance; PinSocket_1x08_P2.54mm_Vertical
DRV_AZ_L: Logique; PinSocket_1x08_P2.54mm_Vertical
DRV_AZ_R: Puissance; PinSocket_1x08_P2.54mm_Vertical
DRV_DEROT_L: Logique; PinSocket_1x08_P2.54mm_Vertical
DRV_DEROT_R: Puissance; PinSocket_1x08_P2.54mm_Vertical
DRV_FOCUS_L: Logique; PinSocket_1x08_P2.54mm_Vertical
DRV_FOCUS_R: Puissance; PinSocket_1x08_P2.54mm_Vertical
D_SCHOTTKY: 1N5822 (3A); D_DO-201AD_P15.24mm_Horizontal
EXT_ALT: Ext. Driver; SolderWire-0.5sqmm_1x04_P4.6mm_D0.9mm_OD2.1mm
EXT_AZ: Ext. Driver; SolderWire-0.5sqmm_1x04_P4.6mm_D0.9mm_OD2.1mm
EXT_DEROT: Ext. Driver; SolderWire-0.5sqmm_1x04_P4.6mm_D0.9mm_OD2.1mm
EXT_FOCUS: Ext. Driver; SolderWire-0.5sqmm_1x04_P4.6mm_D0.9mm_OD2.1mm
H1, H2, H3, H4: M3 Fixation; MountingHole_3.2mm_M3
J_12V: 12V Jack; BarrelJack_Horizontal
J_GPS: GPS SERIAL4; PinHeader_1x04_P2.54mm_Vertical
J_PC_SERIAL: PC SERIAL6; PinHeader_1x04_P2.54mm_Vertical
J_PWR_36V: ALIM 36V DC; TerminalBlock_Phoenix_MKDS-1,5-2-5.08_1x02_P5.08mm_Horizont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
J_RAQUETTE: VERS RAQUETTE; PinHeader_1x04_P2.54mm_Vertical
L_BUCK: 33uH 3A; L_Radial_D12.5mm_P7.00mm_Fastron_09HCP
M_ALT: MOTEUR ALT; TerminalBlock_Phoenix_MKDS-1,5-4-5.08_1x04_P5.08mm_Horizont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
M_AZ: MOTEUR AZ; TerminalBlock_Phoenix_MKDS-1,5-4-5.08_1x04_P5.08mm_Horizont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
M_DEROT: MOTEUR DEROT; TerminalBlock_Phoenix_MKDS-1,5-4-5.08_1x04_P5.08mm_Horizont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
M_FOCUS: MOTEUR FOCUS; TerminalBlock_Phoenix_MKDS-1,5-4-5.08_1x04_P5.08mm_Horizont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
U1: Teensy 4.1; Teensy41
U_LM2596: LM2596-5.0; TO-220-5_Vertical

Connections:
+5V: C_DEC.1, C_OUT.1, DRV_ALT_R.2, DRV_AZ_R.2, DRV_DEROT_R.2, DRV_FOCUS_R.2, J_GPS.3, J_PC_SERIAL.2, J_RAQUETTE.2, L_BUCK.2, U1.48, U_LM2596.4
+36V: C_ALT.1, C_AZ.1, C_DEROT.1, C_FOCUS.1, C_IN.1, DRV_ALT_R.8, DRV_AZ_R.8, DRV_DEROT_R.8, DRV_FOCUS_R.8, J_12V.1, J_PWR_36V.2, U_LM2596.1
ALT_1A: DRV_ALT_R.5, M_ALT.3
ALT_1B: DRV_ALT_R.6, M_ALT.4
ALT_2A: DRV_ALT_R.4, M_ALT.2
ALT_2B: DRV_ALT_R.3, M_ALT.1
ALT_DIR: DRV_ALT_L.8, EXT_ALT.2, U1.8
ALT_EN: DRV_ALT_L.1, EXT_ALT.4, U1.9
ALT_STEP: DRV_ALT_L.7, EXT_ALT.3, U1.7
AZ_1A: DRV_AZ_R.5, M_AZ.3
AZ_1B: DRV_AZ_R.6, M_AZ.4
AZ_2A: DRV_AZ_R.4, M_AZ.2
AZ_2B: DRV_AZ_R.3, M_AZ.1
AZ_DIR: DRV_AZ_L.8, EXT_AZ.2, U1.5
AZ_EN: DRV_AZ_L.1, EXT_AZ.4, U1.6
AZ_STEP: DRV_AZ_L.7, EXT_AZ.3, U1.4
BUZZER: BZ1.1, U1.42
DEROT_1A: DRV_DEROT_R.5, M_DEROT.3
DEROT_1B: DRV_DEROT_R.6, M_DEROT.4
DEROT_2A: DRV_DEROT_R.4, M_DEROT.2
DEROT_2B: DRV_DEROT_R.3, M_DEROT.1
DEROT_DIR: DRV_DEROT_L.8, EXT_DEROT.2, U1.11
DEROT_EN: DRV_DEROT_L.1, EXT_DEROT.4, U1.12
DEROT_STEP: DRV_DEROT_L.7, EXT_DEROT.3, U1.10
FOCUS_1A: DRV_FOCUS_R.5, M_FOCUS.3
FOCUS_1B: DRV_FOCUS_R.6, M_FOCUS.4
FOCUS_2A: DRV_FOCUS_R.4, M_FOCUS.2
FOCUS_2B: DRV_FOCUS_R.3, M_FOCUS.1
FOCUS_DIR: DRV_FOCUS_L.8, EXT_FOCUS.2, U1.14
FOCUS_EN: DRV_FOCUS_L.1, EXT_FOCUS.4, U1.43
FOCUS_STEP: DRV_FOCUS_L.7, EXT_FOCUS.3, U1.13
GND: BZ1.2, C_ALT.2, C_AZ.2, C_DEC.2, C_DEROT.2, C_FOCUS.2, C_IN.2, C_OUT.2, DRV_ALT_R.1, DRV_ALT_R.7, DRV_AZ_R.1, DRV_AZ_R.7, DRV_DEROT_R.1, DRV_DEROT_R.7, DRV_FOCUS_R.1, DRV_FOCUS_R.7, D_SCHOTTKY.2, EXT_ALT.1, EXT_AZ.1, EXT_DEROT.1, EXT_FOCUS.1, J_12V.2, J_12V.3, J_GPS.4, J_PC_SERIAL.1, J_PWR_36V.1, J_RAQUETTE.1, U1.1, U1.47, U_LM2596.3, U_LM2596.5
GPS_RX: J_GPS.1, U1.38
GPS_TX: J_GPS.2, U1.39
PC_RX: J_PC_SERIAL.3, U1.18
PC_TX: J_PC_SERIAL.4, U1.17
RAQUETTE_RX: J_RAQUETTE.3, U1.37
RAQUETTE_TX: J_RAQUETTE.4, U1.36
SW_NODE: D_SCHOTTKY.1, L_BUCK.1, U_LM2596.2

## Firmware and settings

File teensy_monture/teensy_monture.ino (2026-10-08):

/*
 * GotoAndrivetTeensy - Controleur de monture Astro Teensy 4.1 (Protocole OnStep)
 * Auteur : Andrivet Jean-Baptiste
 * 
 * Cablage (Adapté pour Teensy 4.1) :
 * - Moteur AZ  : Step Pin 2, Dir Pin 3
 * - Moteur ALT : Step Pin 5, Dir Pin 6
 * - Buzzer     : Pin 20
 * - Raquette   : Serial3 (Pin 14 TX, Pin 15 RX) @ 38400 baud
 * - Module GPS : Serial4 (Pin 17 TX, Pin 16 RX) @ 9600 baud
 */

IntervalTimer trackingTimer;


#include <math.h>
#include <EEPROM.h>
#include <TinyGPS++.h> // [ADD] Bibliotheque GPS

// === MECANIQUE ===
static uint32_t motorStepsPerRev = 200;
static uint16_t microstep = 128; // Par defaut 128 pour faire 25600 ppr (comme configure sur les switches SW5-SW7=OFF, SW8=ON du M542)
static double   gearRatioAZ = 750.0;
static double   gearRatioALT = 750.0;

static double AZ_PPD  = (double)motorStepsPerRev * microstep * gearRatioAZ / 360.0;
static double ALT_PPD = (double)motorStepsPerRev * microstep * gearRatioALT / 360.0;

static void recalculatePPD() {
  AZ_PPD  = (double)motorStepsPerRev * microstep * gearRatioAZ / 360.0;
  ALT_PPD = (double)motorStepsPerRev * microstep * gearRatioALT / 360.0;
}

uint8_t mountType = 1; // 0=AltAz, 1=ForkEq, 2=GermanEq (configure par defaut en equatorial pour la monture)

// === VITESSES (microsecondes) ===
#define STEP_DELAY_FAST   5       // 200 kHz max - Teensy 4.1 can handle it easily
#define STEP_DELAY_SLOW  100      // 10 kHz  -> 0.3 deg/s manuel
#define MAX_DELAY        500      // 2 kHz   -> 0.06 deg/s depart rampe
#define DEFAULT_SLEW_RATE 3.0
#define ACCEL_STEPS      2000UL
#define ACCEL_MIN_SLEW   (2 * ACCEL_STEPS)

static unsigned long stepDelaySlew = STEP_DELAY_FAST;
static double         maxSlewRate   = DEFAULT_SLEW_RATE;

// === BROCHES ===
#define AZ_STEP   2
#define AZ_DIR    3
#define AZ_EN     4
#define BUZZER_PIN 20
#define BUZZ_FREQ  2000
#define ALT_STEP  5
#define ALT_DIR   6
#define ALT_EN    7

#define DEROT_STEP 8
#define DEROT_DIR  9
#define DEROT_EN   10

#define FOCUS_STEP 11
#define FOCUS_DIR  12
#define FOCUS_EN   21  // [FIX] Pin 21 (libere Pin 13 pour LED_BUILTIN sans conflit)

// === LIMITES ===
#define ALT_MIN  -1.0
#define ALT_MAX  89.5

// === COORDONNEES PAR DEFAUT ===
static double siteLat = 0.0;
static double siteLon = 0.0;
static double utcOff  = 0.0;

// Date/Heure
static int dt_y=2026, dt_m=4, dt_d=26;
static int dt_h=12, dt_mi=0, dt_s=0;
static unsigned long lastClkMs=0;
static bool timeSet = false;           // [FIX 25] False par defaut jusqu'au fix GPS ou :SC/:SL


// === MODELE DE POINTAGE N-ETOILES (IDW) ===
#define MAX_SYNC_POINTS 50
struct SyncPoint {
  double ideal_az;
  double ideal_alt;
  double mach_az;
  double mach_alt;
};
static SyncPoint syncPoints[MAX_SYNC_POINTS];
static int numSyncPoints = 0;
static int syncIndex = 0;

// === ETAT ===
static double currAz=0.0, currAlt=0.0;
static volatile long azPos=0, altPos=0; // Volatile because modified in ISR
static long currRA=0, currDEC=0;
static long inRA=0, inDEC=0;

static double inAlt=0.0, inAz=0.0;
static bool   haveAltAzTarget=false;

static double trkRA=0.0, trkDec=0.0;
static volatile bool tracking=false; // Volatile because read in ISR
static volatile bool slewing=false;  // Volatile because read in ISR
static bool synced=false;
static bool parked=false;
static bool atHome=false;
static volatile bool guiding=false;   // ecrit aussi par l'ISR (fin d'impulsion)
static volatile bool limitHit=false; // Volatile because modified in ISR
static bool alarmActive = false;
static bool buzzerEnabled = true;
static bool azReversed = false;
float parkAlt = 90.0;
float parkAz = 0.0;
static bool altReversed = false;
static uint8_t trackRate=0;
static bool force_tracking_rebase = false;
static bool gpsEnabled = true;
static bool derotEnabled = false;
static double derotPPD = 100.0;
static long derotPos = 0;
static double derotTarget = 0.0;

static bool focusEnabled = false;
bool useSpiDrivers = false; // SPI pour gros Pololu
static uint16_t backlashAz = 0;
static uint16_t backlashAlt = 0;
static int focusSpeed = 1000;
static int8_t focusMove = 0;
static uint8_t slowSpeed=8;
static unsigned long lastTrkMs=0;
static double trkStartLST = 0.0;
static unsigned long azStepInterval = 0;
static unsigned long altStepInterval = 0;
static long azStepsLeft = 0;
static long altStepsLeft = 0;
static int8_t azDirSign = 0;
static int8_t altDirSign = 0;
static unsigned long lastAzStepUs = 0;
static unsigned long lastAltStepUs = 0;

static volatile int8_t azMove=0, altMove=0; // Volatile because read in ISR
static unsigned long lastSlowAz=0, lastSlowAlt=0;

// === SPIRAL SEARCH ===
static bool spiralActive = false;
static unsigned long spiralNextMs = 0;
static int spiralCurrentStep = 0;
static int spiralDirection = 0; 
static int spiralSegmentLength = 1;

// === PERSISTENCE EEPROM ===
const uint16_t EEPROM_ADDR_MAGIC    = 0;
const uint16_t EEPROM_ADDR_PARKED   = 1;
const uint16_t EEPROM_ADDR_SYNCED   = 2;
const uint16_t EEPROM_ADDR_AZ_POS   = 3;
const uint16_t EEPROM_ADDR_ALT_POS  = 7;
const uint16_t EEPROM_ADDR_CURR_RA  = 11;
const uint16_t EEPROM_ADDR_CURR_DEC = 15;
const uint16_t EEPROM_ADDR_TRACKING = 19;
const uint16_t EEPROM_ADDR_SLEW_RATE = 20; 
const uint16_t EEPROM_ADDR_STEPS     = 28; 
const uint16_t EEPROM_ADDR_MICROSTEP = 32; 
const uint16_t EEPROM_ADDR_GEAR_AZ   = 34; 
const uint16_t EEPROM_ADDR_GEAR_ALT  = 42; 
const uint16_t EEPROM_ADDR_MOUNT_TYPE = 50; 
const uint16_t EEPROM_ADDR_BUZZER     = 51; 
const uint16_t EEPROM_ADDR_LATITUDE   = 52; 
const uint16_t EEPROM_ADDR_LONGITUDE  = 60; 
const uint16_t EEPROM_ADDR_REV_AZ     = 68; 
const uint16_t EEPROM_ADDR_REV_ALT    = 69; 
const uint16_t EEPROM_ADDR_PARK_ALT   = 70;
const uint16_t EEPROM_ADDR_PARK_AZ    = 78;
const uint16_t EEPROM_ADDR_DEROT_EN   = 86;
const uint16_t EEPROM_ADDR_DEROT_PPD  = 87;
const uint16_t EEPROM_ADDR_FOCUS_EN   = 95;
const uint16_t EEPROM_ADDR_GPS_EN     = 96;
const uint16_t EEPROM_ADDR_BACKLASH_AZ = 97;
const uint16_t EEPROM_ADDR_BACKLASH_ALT = 99;
const uint16_t EEPROM_ADDR_USE_SPI_DRIVERS = 101;
const byte     EEPROM_MAGIC         = 0x5F;

template <typename T>
void eepromWrite(int address, const T& value) {
  const byte* p = (const byte*)(const void*)&value;
  for (unsigned int i = 0; i < sizeof(value); i++) {
    EEPROM.update(address + i, p[i]);
  }
}

template <typename T>
void eepromRead(int address, T& value) {
  byte* p = (byte*)(void*)&value;
  for (unsigned int i = 0; i < sizeof(value); i++) {
    p[i] = EEPROM.read(address + i);
  }
}

static void saveStateToEEPROM() {
  EEPROM.update(EEPROM_ADDR_MAGIC, EEPROM_MAGIC);
  EEPROM.update(EEPROM_ADDR_PARKED, parked ? 1 : 0);
  EEPROM.update(EEPROM_ADDR_SYNCED, synced ? 1 : 0);
  EEPROM.update(EEPROM_ADDR_TRACKING, 0); 
  EEPROM.update(EEPROM_ADDR_MOUNT_TYPE, mountType);
  EEPROM.update(EEPROM_ADDR_BUZZER, buzzerEnabled ? 1 : 0);
  eepromWrite(EEPROM_ADDR_AZ_POS, azPos);
  eepromWrite(EEPROM_ADDR_ALT_POS, altPos);
  eepromWrite(EEPROM_ADDR_CURR_RA, currRA);
  eepromWrite(EEPROM_ADDR_CURR_DEC, currDEC);
  eepromWrite(EEPROM_ADDR_SLEW_RATE, maxSlewRate); 
  eepromWrite(EEPROM_ADDR_STEPS, motorStepsPerRev);
  eepromWrite(EEPROM_ADDR_MICROSTEP, microstep);
  eepromWrite(EEPROM_ADDR_GEAR_AZ, gearRatioAZ);
  eepromWrite(EEPROM_ADDR_GEAR_ALT, gearRatioALT);
  eepromWrite(EEPROM_ADDR_LATITUDE, siteLat);
  eepromWrite(EEPROM_ADDR_LONGITUDE, siteLon);
  EEPROM.update(EEPROM_ADDR_REV_AZ, azReversed ? 1 : 0);
  EEPROM.update(EEPROM_ADDR_REV_ALT, altReversed ? 1 : 0);
  eepromWrite(EEPROM_ADDR_PARK_ALT, parkAlt);
  eepromWrite(EEPROM_ADDR_PARK_AZ, parkAz);
  EEPROM.update(EEPROM_ADDR_DEROT_EN, derotEnabled ? 1 : 0);
  eepromWrite(EEPROM_ADDR_DEROT_PPD, derotPPD);
  EEPROM.update(EEPROM_ADDR_FOCUS_EN, focusEnabled ? 1 : 0);
  EEPROM.update(EEPROM_ADDR_GPS_EN, gpsEnabled ? 1 : 0);
  eepromWrite(EEPROM_ADDR_BACKLASH_AZ, backlashAz);
  eepromWrite(EEPROM_ADDR_BACKLASH_ALT, backlashAlt);
  EEPROM.update(EEPROM_ADDR_USE_SPI_DRIVERS, useSpiDrivers ? 1 : 0);
}

static void loadStateFromEEPROM() {
  if (EEPROM.read(EEPROM_ADDR_MAGIC) == EEPROM_MAGIC) {
    mountType = EEPROM.read(EEPROM_ADDR_MOUNT_TYPE);
    buzzerEnabled = (EEPROM.read(EEPROM_ADDR_BUZZER) == 1);
    eepromRead(EEPROM_ADDR_SLEW_RATE, maxSlewRate); 
    eepromRead(EEPROM_ADDR_STEPS, motorStepsPerRev);
    eepromRead(EEPROM_ADDR_MICROSTEP, microstep);
    eepromRead(EEPROM_ADDR_GEAR_AZ, gearRatioAZ);
    eepromRead(EEPROM_ADDR_GEAR_ALT, gearRatioALT);
    eepromRead(EEPROM_ADDR_LATITUDE, siteLat);
    eepromRead(EEPROM_ADDR_LONGITUDE, siteLon);
    azReversed = (EEPROM.read(EEPROM_ADDR_REV_AZ) == 1);
    altReversed = (EEPROM.read(EEPROM_ADDR_REV_ALT) == 1);
    eepromRead(EEPROM_ADDR_PARK_ALT, parkAlt);
    eepromRead(EEPROM_ADDR_PARK_AZ, parkAz);
    derotEnabled = (EEPROM.read(EEPROM_ADDR_DEROT_EN) == 1);
    eepromRead(EEPROM_ADDR_DEROT_PPD, derotPPD);
    focusEnabled = (EEPROM.read(EEPROM_ADDR_FOCUS_EN) == 1);
    gpsEnabled = (EEPROM.read(EEPROM_ADDR_GPS_EN) == 1);
    eepromRead(EEPROM_ADDR_BACKLASH_AZ, backlashAz);
    eepromRead(EEPROM_ADDR_BACKLASH_ALT, backlashAlt);
    useSpiDrivers = (EEPROM.read(EEPROM_ADDR_USE_SPI_DRIVERS) == 1);
    if(backlashAz > 10000) backlashAz = 0;
    if(backlashAlt > 10000) backlashAlt = 0;
    recalculatePPD();
    if(isnan(derotPPD) || derotPPD < 1.0) derotPPD = 100.0;
    if (isnan(parkAlt) || parkAlt < -90.0 || parkAlt > 90.0) parkAlt = (mountType >= 1) ? 90.0 : 0.0;
    if (isnan(parkAz) || parkAz < 0.0 || parkAz > 360.0) parkAz = 0.0;
    
    if (isnan(siteLat) || siteLat < -90.0 || siteLat > 90.0 ||
        isnan(siteLon) || siteLon < -180.0 || siteLon > 180.0) {
      siteLat = 0.0;
      siteLon = 0.0;
    }
    
    if (motorStepsPerRev < 100 || motorStepsPerRev > 100000UL ||
        microstep < 1 || microstep > 512 ||
        isnan(gearRatioAZ) || gearRatioAZ < 1.0 || gearRatioAZ > 10000.0 ||
        isnan(gearRatioALT) || gearRatioALT < 1.0 || gearRatioALT > 10000.0 ||
        isnan(maxSlewRate) || maxSlewRate < 0.1 || maxSlewRate > 25.0 ||
        mountType > 2) 
    {
      motorStepsPerRev = 200;
      microstep = 125; 
      gearRatioAZ = 750.0;
      gearRatioALT = 750.0;
      maxSlewRate = DEFAULT_SLEW_RATE;
      mountType = 2; 
      buzzerEnabled = true;
    }
  } else {
    motorStepsPerRev = 200;
    microstep = 125; 
    gearRatioAZ = 750.0;
    gearRatioALT = 750.0;
    maxSlewRate = DEFAULT_SLEW_RATE;
    mountType = 2; 
    buzzerEnabled = true;
    azReversed = false;
    altReversed = false;
    parkAlt = (mountType >= 1) ? 90.0 : 0.0;
    parkAz = 0.0;
    derotEnabled = false;
    derotPPD = 100.0;
    focusEnabled = false;
    saveStateToEEPROM();
  }

  parked = true;
  synced = true;
  tracking = false;

  recalculatePPD();

  currAz = 0.0;
  currAlt = (mountType >= 1) ? 90.0 : 0.0;
  azPos = 0;
  altPos = (long)(currAlt * ALT_PPD);

  currDEC = (mountType >= 1) ? 90L * 3600L : 0L;
  currRA = (long)(lst() * 3600.0);

  trkRA = (double)currRA / 3600.0;
  trkDec = (double)currDEC / 3600.0;

  double d = 1.0e6 / (AZ_PPD * maxSlewRate);
  if(d < (double)STEP_DELAY_FAST) d = STEP_DELAY_FAST;
  if(d > (double)MAX_DELAY)       d = MAX_DELAY;
  stepDelaySlew = (unsigned long)d;
}

static char lxRA[12]="00:00:00#";
static char lxDEC[14]="+90*00:00#";

#define CMD_MAX 40
static char cmdUsb[CMD_MAX];   static uint8_t ciUsb=0;
static char cmdRj[CMD_MAX];    static uint8_t ciRj=0;
static char cmdPc[CMD_MAX];    static uint8_t ciPc=0;

static Print* slewOut = nullptr;

static void processCmd(const char* cmd, uint8_t ci, Print& out);
static void sendGU(Print& out);
static void handleGX(const char* cmd, Print& out);
static void handleGBE(Print& out);
static int slewToAA(double tAlt, double tAz);
void updateBuzzer();
void triggerConnectBeep();
void triggerGpsFixBeep();

// ======================== HELPERS DATE =====================

static uint8_t daysInMonth(int m, int y) {
  static const uint8_t d[] = {31,28,31,30,31,30,31,31,30,31,30,31};
  if(m < 1 || m > 12) return 30;
  if(m == 2 && ((y%4==0 && y%100!=0) || y%400==0)) return 29;
  return d[m-1];
}

static void getUTC(int *uy, int *um, int *ud, int *uh, int *umi, int *us) {
  double utcH = dt_h + dt_mi/60.0 + dt_s/3600.0 - utcOff;
  int dayOff = 0;
  while(utcH < 0.0)   { utcH += 24.0; dayOff--; }
  while(utcH >= 24.0) { utcH -= 24.0; dayOff++; }
  *uh  = (int)utcH;
  double rem = (utcH - *uh) * 60.0;
  *umi = (int)rem;
  *us  = (int)((rem - *umi) * 60.0);
  *uy = dt_y; *um = dt_m; *ud = dt_d + dayOff;
  while(*ud < 1) {
    (*um)--;
    if(*um < 1) { *um = 12; (*uy)--; }
    *ud += daysInMonth(*um, *uy);
  }
  while(*ud > daysInMonth(*um, *uy)) {
    *ud -= daysInMonth(*um, *uy);
    (*um)++;
    if(*um > 12) { *um = 1; (*uy)++; }
  }
}

// ======================== GPS ADAFRUIT =====================
TinyGPSPlus gps;

static bool gpsHasFixedOnce = false;
static unsigned long gpsSearchStart = 0;

static void handleGPS() {
  if (gpsSearchStart == 0) gpsSearchStart = millis();

  // Desactivation auto apres 10 min (600 000 ms) sans fix
  if (gpsEnabled && !gpsHasFixedOnce) {
    if (millis() - gpsSearchStart > 600000UL) {
      gpsEnabled = false; 
    }
  }

  while (Serial4.available() > 0) {
    char c = Serial4.read();
    if (!gpsEnabled) continue;

    if (gps.encode(c)) {
      if (!gpsHasFixedOnce && gps.location.isValid() && gps.date.isValid()) {
        gpsHasFixedOnce = true;
        triggerGpsFixBeep();
      }
      // Mise a jour des coordonnees
      if (gps.location.isValid() && gps.location.isUpdated()) {
        siteLat = gps.location.lat();
        siteLon = gps.location.lng();
      }
      
      // Mise a jour de l'heure
      if (gps.time.isValid() && gps.date.isValid() && gps.time.isUpdated()) {
        int new_y = gps.date.year();
        int new_m = gps.date.month();
        int new_d = gps.date.day();
        int new_h = gps.time.hour();
        int new_mi = gps.time.minute();
        int new_s = gps.time.second();

        // Le GPS donne l'heure UTC. Application de l'utcOff pour l'heure locale
        int offsetH = (int)utcOff;
        new_h += offsetH;

        // Wrap-around simple pour ajustement du jour selon l'heure locale
        if (new_h >= 24) {
          new_h -= 24;
          new_d++;
          if (new_d > daysInMonth(new_m, new_y)) {
            new_d = 1;
            new_m++;
            if (new_m > 12) { new_m = 1; new_y++; }
          }
        } else if (new_h < 0) {
          new_h += 24;
          new_d--;
          if (new_d < 1) {
            new_m--;
            if (new_m < 1) { new_m = 12; new_y--; }
            new_d = daysInMonth(new_m, new_y);
          }
        }

        dt_y = new_y;
        dt_m = new_m;
        dt_d = new_d;
        dt_h = new_h;
        dt_mi = new_mi;
        dt_s = new_s;

        lastClkMs = millis(); // Resynchronisation de l'horloge interne
        timeSet = true;       // Deverrouillage des commandes GoTo !
      }
    }
  }
}

// ======================== ASTRO ============================

static void jday_split(long *days_whole, double *days_frac) {
  int uy, um, ud, uh, umi, us;
  getUTC(&uy, &um, &ud, &uh, &umi, &us);
  
  unsigned long ms = millis() - lastClkMs;
  if (ms > 2000) ms = 0;
  double sub_sec = (double)ms / 1000.0;
  
  double h = uh + umi/60.0 + (us + sub_sec)/3600.0;
  int y = uy, m = um;
  if(m <= 2) { y--; m += 12; }
  long A = y / 100;
  long B = A / 4;
  long C = 2 - A + B;
  long tempY = y + 4716;
  long E_val = (tempY * 365) + (tempY / 4);
  long tempM = m + 1;
  long F_val = (tempM * 306) / 10;
  
  long jd_whole = C + E_val + F_val + ud - 1524;
  
  *days_whole = jd_whole - 2451545;
  *days_frac = -0.5 + h/24.0;
}

static double jday() {
  long whole;
  double frac;
  jday_split(&whole, &frac);
  return (double)whole + frac + 2451545.0;
}

static double lst_offset(double offset_sec) {
  long whole;
  double frac;
  jday_split(&whole, &frac);
  frac += offset_sec / 86400.0;
  
  double jd_diff = (double)whole + frac;
  double T = jd_diff / 36525.0;
  
  double w_term = 0.98564736629 * (double)whole;
  double w_term_mod = fmod(w_term, 360.0);
  if (w_term_mod < 0) w_term_mod += 360.0;
  
  double frac_term = 360.98564736629 * frac;
  double T_term = 0.000387933 * T * T;
  
  double g = 280.46061837 + w_term_mod + frac_term + T_term;
  g = fmod(g, 360.0); if(g < 0) g += 360.0;
  g = fmod(g + siteLon, 360.0); if(g < 0) g += 360.0;
  return g / 15.0;
}

static double lst() {
  return lst_offset(0.0);
}

static double getHourAngle(double ra) {
  double current_lst = lst();
  double ha_hours;
  if (tracking && trkStartLST > 0.0) {
    double scale = 1.0;
    if (trackRate == 1)      scale = 0.976327; 
    else if (trackRate == 2) scale = 0.997270; 
    double elapsed = current_lst - trkStartLST;
    if (elapsed < -12.0) elapsed += 24.0;
    if (elapsed > 12.0)  elapsed -= 24.0;
    ha_hours = (trkStartLST - ra) + elapsed * scale;
  } else {
    ha_hours = current_lst - ra;
  }
  double ha = fmod(ha_hours * 15.0, 360.0);
  if (ha < 0.0) ha += 360.0;
  return ha;
}
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
void loop() {
  clk();
  handleGPS(); // [ADD] On ecoute le GPS et on met a l'heure

  // === SPIRAL SEARCH LOGIC ===
  if (spiralActive) {
    if (millis() >= spiralNextMs) {
      azMove = 0; altMove = 0;
      if (spiralDirection == 0) azMove = -1; // East / Right
      else if (spiralDirection == 1) altMove = 1; // North / Up
      else if (spiralDirection == 2) azMove = 1;  // West / Left
      else if (spiralDirection == 3) altMove = -1; // South / Down
      
      unsigned long duration = spiralSegmentLength * 1000UL; // 1s per segment unit
      spiralNextMs = millis() + duration;
      
      spiralDirection = (spiralDirection + 1) % 4;
      spiralCurrentStep++;
      if (spiralCurrentStep >= 2) {
        spiralCurrentStep = 0;
        spiralSegmentLength++;
      }
    }
  }

  // Mouvement lent (boutons E/W/N/S)
  if(!slewing && !parked){
    unsigned long now=micros();
    unsigned long nowMs=millis();
    
    static int8_t azActiveMove = 0;
    static float azFrequency = 0.0;
    float f_min = 1.0e6 / MAX_DELAY;
    
    if (azMove != 0) {
      azActiveMove = azMove;
      azFrequency = f_min;
    } else {
      azActiveMove = 0;
      azFrequency = 0.0;
    }
    
    static int8_t altActiveMove = 0;
    static float altFrequency = 0.0;
    
    if (altMove != 0) {
      altActiveMove = altMove;
      altFrequency = f_min;
    } else {
      altActiveMove = 0;
      altFrequency = 0.0;
    }
    
    if (azActiveMove != 0 || altActiveMove != 0) {
        unsigned long delayAz = azActiveMove ? (unsigned long)(1.0e6 / azFrequency) : 0xFFFFFFFF;
        unsigned long delayAlt = altActiveMove ? (unsigned long)(1.0e6 / altFrequency) : 0xFFFFFFFF;
        if (delayAz < 5) delayAz = 5;
        if (delayAlt < 5) delayAlt = 5;
        
        while (true) {
            unsigned long nowUs = micros();
            bool azReady = azActiveMove && (nowUs - lastSlowAz >= delayAz);
            bool altReady = altActiveMove && (nowUs - lastSlowAlt >= delayAlt);
            
            if (azReady || altReady) {
                if (azReady) {
                    lastSlowAz = nowUs;
                    setDirAz(azActiveMove);
                    stepPulse(AZ_STEP); azPos+=azActiveMove;
                }
                if (altReady) {
                    lastSlowAlt = nowUs;
                    double nA=(double)(altPos+altActiveMove)/ALT_PPD;
                    bool allowed = false;
                    if (nA >= ALT_MIN && nA <= ALT_MAX) allowed = true;
                    else if (nA < ALT_MIN && altActiveMove > 0) allowed = true;
                    else if (nA > ALT_MAX && altActiveMove < 0) allowed = true;
                    
                    if(mountType >= 1 || allowed){
                        setDirAlt(altActiveMove);
                        stepPulse(ALT_STEP); altPos+=altActiveMove;
                    } else {
                        limitHit=true;
                        altActiveMove = 0;
                        altFrequency = 0.0;
                    }
                }
                break;
            }
            if (Serial3.available() > 0 || Serial.available() > 0 || Serial6.available() > 0) {
                break;
            }
        }
    }
    
    static bool wasMovingSlow = false;
    bool currentlyMovingSlow = (azMove != 0 || altMove != 0 || azActiveMove != 0 || altActiveMove != 0);
    if (currentlyMovingSlow) {
      static unsigned long lastManualUpdMs = 0;
      if (millis() - lastManualUpdMs >= 200) {
        lastManualUpdMs = millis();
        updatePos();
      }
      wasMovingSlow = true;
    } else if (wasMovingSlow) {
      updatePos();
      if (tracking) {
        force_tracking_rebase = true;
      }
      saveStateToEEPROM();
      wasMovingSlow = false;
    }
  }

  
  doTrack();
  updateBuzzer();

  // Handle Derotator
  if(derotEnabled && mountType == 0) { // Only in Alt-Az
    long stepsPerRev = (long)(360.0 * derotPPD);
    long targetPos = (long)(derotTarget * derotPPD);
    long diff = targetPos - derotPos;
    if (stepsPerRev > 0) {
      while (diff > stepsPerRev / 2) diff -= stepsPerRev;
      while (diff < -stepsPerRev / 2) diff += stepsPerRev;
    }
    if(abs(diff) > 0) {
      digitalWrite(DEROT_EN, LOW);
      digitalWrite(DEROT_DIR, diff > 0 ? HIGH : LOW);
      digitalWrite(DEROT_STEP, HIGH);
      delayMicroseconds(10);
      digitalWrite(DEROT_STEP, LOW);
      derotPos += (diff > 0 ? 1 : -1);
      delayMicroseconds(200);
    } else {
      digitalWrite(DEROT_EN, HIGH);
    }
  }

  // Handle Focus
  if(focusEnabled && focusMove != 0) {
    digitalWrite(FOCUS_DIR, focusMove > 0 ? HIGH : LOW);
    digitalWrite(FOCUS_STEP, HIGH);
    delayMicroseconds(10);
    digitalWrite(FOCUS_STEP, LOW);
    delayMicroseconds(focusSpeed);
  }

  serveStream(Serial,  Serial,  cmdUsb, ciUsb);

  serveStream(Serial3, Serial3, cmdRj,  ciRj);
  serveStream(Serial6, Serial6, cmdPc,  ciPc);
}

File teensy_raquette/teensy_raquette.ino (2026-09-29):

/*
 * GotoAndrivet - Teensy 4.1 Raquette
 * Auteur : Andrivet Jean-Baptiste
 * Firmware UI (LCD + boutons)
 * 
 * Cablage RJ11 (Teensy raquette <-> Mega) :
 *
 *   Pin RJ11   Signal                    Connexion
 *   -------    ------                    ---------
 *     1        GND                       Mega GND  <-> Teensy GND
 *     2        5V  (alim Teensy)         Mega 5V    -> Teensy VIN
 *     3        TX  (Teensy -> Mega)      Teensy Pin 1 (TX1) -> Mega Pin 15 (RX3)
 *     4        RX  (Mega -> Teensy)      Mega Pin 14 (TX3)  -> Teensy Pin 0 (RX1)
 *
 * ALIMENTATION : Le Teensy est alimente par la pin 5V du Mega via VIN.
 *   Le Mega doit etre alimente par barrel jack (7-12V) pour fournir
 *   assez de courant (regulateur ~800mA, conso totale ~250mA).
 *   ATTENTION : ne pas brancher l'USB du Teensy en meme temps que le
 *   VIN est alimente, sauf si le pad VUSB est coupe sur le Teensy.
 */

#include <Arduino.h>
#include <Wire.h>
#include <LiquidCrystal_I2C.h>
#include <EEPROM.h>
#include "mini_ephem.h"

enum CatID { CAT_MESSIER=0, CAT_NGC, CAT_IC, CAT_PK, CAT_CALDWELL, CAT_BSC, CAT_SYSSOL, CAT_COUNT };
bool isEnglish = false;
bool displayRaDec = true;
bool temp_displayRaDec = true;
#define CHAR_LEFT  0x7F
#define CHAR_RIGHT 0x7E

int dt_y=2026, dt_m=1, dt_d=1;
int dt_hr=12, dt_min=0, dt_sec=0;
int cgo_ra_h=0, cgo_ra_m=0, cgo_ra_s=0;
int cgo_dec_d=0, cgo_dec_m=0, cgo_dec_s=0;
bool cgo_dec_neg=false;
float obs_lat=45.0, obs_lon=0.0;
bool timeFetched = false;

// ============================================================
// SECTION CATALOGUES ASTRONOMIQUES (intégrés en PROGMEM)
// ============================================================

#define OBJ_GALAXY       0
#define OBJ_OPEN_CLUSTER 1
#define OBJ_GLOB_CLUSTER 2
#define OBJ_NEBULA       3
#define OBJ_PLAN_NEBULA  4
#define OBJ_SUPERNOVA    5
#define OBJ_DOUBLE_STAR  6
#define OBJ_ASTERISM     7
#define OBJ_STAR         8

struct DeepSkyObject {
    uint16_t id;
    float    ra;    
    float    dec;   
    int16_t  mag;   
    uint8_t  type;
};

struct StarObject {
    uint16_t id;
    float    ra;
    float    dec;
    int16_t  mag;   
    uint8_t  type;  
    char     name[12];
};

const char* const typeGal = "Galaxie     ";
const char typeOC[]  PROGMEM = "Amas ouvert ";
const char typeGC[]  PROGMEM = "Amas globul.";
const char* const typeNeb = "Nebuleuse   ";
const char typePN[]  PROGMEM = "Neb.Planet. ";
const char typeSN[]  PROGMEM = "Reste SNova ";
const char typeDS[]  PROGMEM = "Etoile dble ";
const char* const typeAst = "Asterisme   ";
const char typeStar[] PROGMEM= "Etoile      ";

const char* const OBJ_TYPE_NAMES[] = {
    typeGal, typeOC, typeGC, typeNeb, typePN, typeSN, typeDS, typeAst, typeStar
};

const char* getTypeName(uint8_t type) {
    if (type >= 9) type = 0;
    if (isEnglish) {
        const char* const OBJ_TYPE_NAMES_EN[] = {
            "Galaxy      ", "Open Cluster", "Glob.Cluster", "Nebula      ", "Plan.Nebula ", "Supernova R.", "Double Star ", "Asterism    ", "Star        "
        };
        return OBJ_TYPE_NAMES_EN[type];
    }
    return OBJ_TYPE_NAMES[type];
}

// ---------- M 110 objets ----------
const DeepSkyObject catalogM[] PROGMEM = {
    {    1,    5.5756f,   22.0144f,   85, 5},
    {    2,   21.5575f,   -0.8233f,   63, 2},
    {    3,   13.7031f,   28.3756f,   62, 2},
    {    4,   16.3931f,  -26.5253f,   56, 2},
    {    5,   15.3092f,    2.0828f,   65, 2},
    {    6,   17.6725f,  -32.2189f,   51, 1},
    {    7,   17.8975f,  -34.7928f,   33, 1},
    {    8,   18.0603f,  -24.3867f,   60, 3},
    {    9,   17.3200f,  -18.5161f,   78, 2},
    {   10,   16.9525f,   -4.0994f,   66, 2},
    {   11,   18.8514f,   -6.2667f,   58, 1},
    {   12,   16.7872f,   -1.9483f,   68, 2},
    {   13,   16.6947f,   36.4614f,   58, 2},
    {   14,   17.6267f,   -3.2458f,   77, 2},
    {   15,   21.4994f,   12.1669f,   62, 2},
    {   16,   18.3072f,  -13.7789f,   60, 1},
    {   17,   18.3406f,  -16.1767f,   60, 3},
    {   18,   18.3328f,  -17.1017f,   69, 1},
    {   19,   17.0436f,  -26.2681f,   70, 2},
    {   20,   18.0283f,  -23.0300f,   82, 3},
    {   21,   18.0703f,  -22.4900f,   58, 1},
    {   22,   18.6067f,  -23.9033f,   51, 2},
    {   23,   17.9483f,  -19.0167f,   52, 1},
    {   24,   18.2833f,  -18.5333f,   45, 1},
    {   25,   18.5297f,  -19.1167f,   46, 1},
    {   26,   18.7550f,   -9.3833f,   80, 1},
    {   27,   19.9933f,   22.7211f,   74, 4},
    {   28,   18.4089f,  -24.8700f,   78, 2},
    {   29,   20.3989f,   38.5333f,   71, 1},
    {   30,   21.6728f,  -23.1792f,   72, 2},
    {   31,    0.7122f,   41.2692f,   35, 0},
    {   32,    0.7117f,   40.8653f,   82, 0},
    {   33,    1.5642f,   30.6603f,   59, 0},
    {   34,    2.7014f,   42.7833f,   51, 1},
    {   35,    6.1483f,   24.3333f,   52, 1},
    {   36,    5.6017f,   34.1333f,   60, 1},
    {   37,    5.8717f,   32.5533f,   56, 1},
    {   38,    5.4786f,   35.8333f,   67, 1},
    {   39,   21.5300f,   48.4333f,   49, 1},
    {   40,   12.3700f,   58.0833f,   90, 6},
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
};
const uint16_t MESSIER_COUNT = 110;
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

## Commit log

2026-06-23 Add firmware flashing feature to configurator and fix Teensy compilation
    [goto_universal_config_tool.py]
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2026-06-27 Fix: Ajout effectif de la synchronisation sur la raquette Python
    [raquette_virtuelle.py]
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2026-06-27 Fix: Crash au lancement de la raquette
    [raquette_virtuelle.py]
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2026-06-27 UI: Affichage dynamique Ratio AZ/ALT ou RA/DEC selon type monture + Fix affichage Sync
    [raquette_virtuelle.py]
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2026-06-27 Fix: La liste des objets etait ecrasee par l'affichage LCD, empechant les asterisques d'apparaitre
    [raquette_virtuelle.py]
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2026-06-27 Fix: Plantage de la raquette virtuelle avec les couleurs LCD
    [raquette_virtuelle.py]
2026-06-27 Fix: Annulation de l'ecran RVB (l'ecran physique est monochrome rouge) et ajout animation flocon
    [raquette_virtuelle.py]
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2026-06-27 Fix: Plantage du configurateur (traductions manquantes)
    [goto_universal_config_tool.py]
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2026-06-27 Feat/Fix: Mise a jour auto de la position parking selon le type de monture
    [goto_universal_config_tool.py]
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2026-06-28 Fix UI freeze during flash by running subprocess in a thread
    [goto_universal_config_tool.py]
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2026-07-07 Fix silent ignore of GOTO in process_queue
    [raquette_virtuelle.py]
2026-07-07 Fix ETA calculation speed parsing
    [raquette_virtuelle.py]
2026-07-07 Fix max speed division by 10
    [raquette_virtuelle.py]
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2026-07-07 Fix ETA missing 2.5s from acceleration ramp
    [raquette_virtuelle.py]
2026-07-07 Fix ETA math to use axis distance instead of great circle distance
    [raquette_virtuelle.py]
2026-07-07 Sync mechanical configuration to Arduino on connection to fix speed mismatch
    [raquette_virtuelle.py]
2026-07-07 Fix mechanical sync commands (BMm to BSm) and remove blocking read_until('#') since these commands only return '1'
    [raquette_virtuelle.py]
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2026-07-07 Fix massive Arduino CPU bottleneck by reducing serial telemetry rate during slews
    [raquette_virtuelle.py]
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2026-07-07 Remove the 215us CPU overhead limit since the serial spam fix allowed the Arduino to run at full speed again
    [raquette_virtuelle.py]
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2026-07-07 Final revert: Set CPU overhead back to 35us since the serial spam fix successfully restored full motor speed
    [raquette_virtuelle.py]
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2026-07-07 Fix USB port selection priority for Mega, adapt UI to 4x20 layout for Teensy, fix ETA math in Virtual Raquette
    [raquette_virtuelle.py]
2026-07-07 Show AltAz instead of RaDec on main screens if mount is AltAz, and fix missing 4-line UI in Teensy menu
    [raquette_virtuelle.py]
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2026-07-09 Fix update badge showing on first run
    [goto_mega_config_tool.py]
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2026-07-09 Fix python executable path for ZWO camera scripts inside venv
    [polar_alignment_ui.py]
2026-07-09 Fix remaining instances of wrong python path for ZWO scripts
    [goto_mega_config_tool.py]
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2026-07-09 Fix ZWO_CaptureError with a retry loop
    [polar_alignment_ui.py]
2026-07-09 Use explicit venv python to fix traceback when run from terminal
    [goto_mega_config_tool.py]
2026-07-09 Fix python paths for raquette virtuelle and add ephem requirement
    [goto_mega_config_tool.py, install_linux.py]
2026-07-09 Fix ZWO capture timeout on long exposures with low bandwidth
    [goto_mega_config_tool.py, polar_alignment_ui.py]
2026-07-10 Fix absolute paths to use Path.home() for raquette_virtuelle and python env
    [goto_mega_config_tool.py]
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2026-07-10 Fix Celestrak timeout and add AMSAT fallback for TLE
    [goto_mega_config_tool.py]
2026-07-11 Fix ISS TLE download using live.ariss.org as primary source
    [goto_mega_config_tool.py]
2026-07-11 Fix wait at horizon: Send GOTO to current alt/az RA/DEC and disable tracking until rise time
    [raquette_virtuelle.py]
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2026-07-11 Fix python bug: remove local import time
    [raquette_virtuelle.py]
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2026-07-11 Fix Teensy GoTo response parsing and align Virtual Raquette Menus
    [raquette_virtuelle.py]
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2026-07-15 Correction bug d'affichage : nettoyage de l'écran et affichage des 2 choix
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2026-07-15 Correction d'affichage : nettoyage de l'écran pour les menus Vitesse, Alignement et Parking
2026-07-16 Correction bugs de portée lambda (NameError), correction gmtime dans raquette_virtuelle et affichage ETAT
    [goto_mega_config_tool.py, polar_alignment_ui.py, raquette_virtuelle.py]
2026-07-16 Fix remaining lambda scoping issue on line 163
    [polar_alignment_ui.py]
2026-07-16 Corrige le bug du chronometre de GOTO (Temps estime)
    [raquette_virtuelle.py]
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2026-07-16 Correction de la vitesse et des unites du simulateur
    [raquette_virtuelle.py]
2026-07-16 Correction des avertissements cosmetiques de pyflakes (variables inutilisees, f-string)
    [raquette_virtuelle.py]
2026-07-16 Correction de la boucle de simulation (wrap AD et contrainte DEC)
    [raquette_virtuelle.py]
2026-07-17 Fix boot connection bug (accept OnStep), fix sticky manual move with Qn/Qs/Qe/Qw, bump to Mega v9.2 and Raquette v6.4
    [goto_mega_mega.ino]
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2026-07-19 Fix Teensy buzzer pin to 20 and restore focuser/derotator pins in documentation
    [fix_pins.py, teensy_monture.ino]
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2026-07-19 Fix asymmetric motor deceleration by implementing Bresenham line algorithm
    [mega_monture.ino, teensy_monture.ino]
2026-07-19 Fix DEC tracking wrap bug in Equatorial mode and remove ramps for manual moves
    [goto_andrivet_config_tool.py, mega_monture.ino, teensy_monture.ino]
2026-07-19 Fix manual recentering jump by rebasing tracking target
    [mega_monture.ino, teensy_monture.ino]
2026-07-19 Fix tracking jump when syncing coordinates
    [mega_monture.ino, teensy_monture.ino]
2026-07-19 Fix tracking jump when auto-guiding
    [mega_monture.ino, teensy_monture.ino]
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2026-07-20 Fix asterisks issue by syncing LST at startup
    [teensy_raquette.ino]
2026-07-20 Fix status string display and add scrolling
    [teensy_raquette.ino]
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2026-07-20 Fix KStars GoTo interference from Raquette EMI noise
    [mega_monture.ino, teensy_raquette.ino]
2026-07-20 Fix noise during GoTo
    [teensy_raquette.ino]
2026-07-20 Fix target altitude calculation for EQ mounts
    [mega_monture.ino]
2026-07-20 Fix: Correction globale du mode Fork, alarme temperature, et parking AltAz
    [mega_monture.ino]
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2026-07-20 Fix: Correction du bug critique de limitation horizon en Goto Fork (targetAlt etait confondu avec l'AD/DEC)
    [mega_monture.ino]
2026-07-20 Fix: Remplacement de Fork# par ForkEq# pour satisfaire le driver KStars
    [mega_monture.ino]
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2026-07-26 Guidage Mega: portage du correctif non bloquant
    Même défaut que sur la cible Teensy : le handler :Mg écrivait DIR une
    fois puis bouclait en bloquant, pendant que ISR(TIMER1_COMPA_vect)
    réécrivait DIR à chaque pas de suivi.
    - accumulateurs az/alt signés, suivi et guidage sommés dans l'ISR
    - vitesse de guidage dérivée de AZ_PPD/ALT_PPD et du sidéral
    - :Mg non bloquant, recalage doux de trkRA/trkDec après impulsion
    - dirWrite() en accès direct au port (sbi/cbi, atomique donc appelable
    depuis l'ISR), avec repli digitalWrite si les broches changent
    - largeur d'impulsion extraite en STEP_PULSE_US, valeur inchangée à 10 us
    [mega_monture.ino]
2026-07-26 Guidage: DIR pilote par un helper unique par axe
    Le cache lastDir introduit avec stepAxis n'etait consulte que par l'ISR,
    alors que slewToAA() et le mouvement manuel ecrivaient encore DIR
    directement. Apres un GOTO vers un azimut decroissant, lastDirAz valait
    toujours +1 pendant que la broche etait passee a LOW : stepAxis sautait
    l'ecriture et le suivi repartait a l'envers, azPos continuant de compter
    a l'endroit. En sideral le sens ne s'inverse jamais, donc l'ecart ne se
    rattrapait jamais seul. Regression plus large que le bug corrige : elle
    touchait chaque GOTO, pas seulement les impulsions de guidage.
    Plutot que d'invalider le cache aux quatre sites (fragile : tout code
    futur devrait y p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
    [mega_monture.ino, teensy_monture.ino]
2026-07-26 Guidage: fermeture des deux fuites d'etat
    1. Ticks jamais consommes. guideTicksAz/Alt n'etaient decrementes que sous
    motionOK. Un :Mg recu suivi coupe armait les ticks sans jamais les
    ecouler : guiding restait vrai indefiniment (le 'G' du statut ne
    retombait plus) et l'impulsion periemee repartait au rallumage du suivi.
    - :Mg refuse desormais si !tracking, en plus de alarmActive/slewing
    - le decompte court quoi qu'il arrive dans l'ISR, seule la contribution
    au mouvement reste conditionnee par motionOK. Une impulsion a donc une
    duree de vie bornee (5 s max) meme si l'etat change en cours de route :
    alarme levee, GOTO lance, bouton de direction tenu.
    2. guiding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
    [mega_monture.ino, teensy_monture.ino]
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2026-07-26 Retire mega_monture/fix2.py du suivi
    Embarque par erreur dans 783a695 par un git add -A trop large. C'est un
    script de patch one-shot, du meme genre que les patch_*.py de la racine,
    qui n'ont pas leur place dans le depot. Le fichier reste sur le disque.
2026-07-26 Compatibilite KStars/Ekos: corrige :GU# et :GXEM#
    Confronte au source du driver INDI (scratch/lx200_OnStep_full.cpp), qui
    cherche les lettres de :GU# par strstr() sur toute la chaine et lit ses
    trois derniers caracteres positionnellement.
    1. Monture fourche vue parquee en permanence. La lettre de type ForkEq
    etait 'P', or le driver fait strstr(OSStat,"P") -> TrackState =
    SCOPE_PARKED + SetParked(true) a chaque poll. La monture etait
    inutilisable depuis Ekos. Meme effet dans goto_andrivet.py, qui fait
    parked = 'P' in f. Les lettres suivent maintenant la convention du
    driver : E = GEM, K = fourche, A = AltAz.
    Au passage, 'G' pour GermanEq faisait croire a un guidage permane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
    [mega_monture.ino, teensy_monture.ino]
2026-07-26 Guidage: commande :Rg pour regler la vitesse de guidage
    guideRate etait fige a 0,5x sideral sans moyen de le changer, et la valeur
    etait dupliquee en dur dans les reponses :GX90#/:GX91#.
    :Rg<x.xx># la regle en multiple du sideral, borne a [0,1 ; 1,0], reponse
    '1' ou '0'. :GX90# et :GX91# suivent maintenant la variable, ainsi que
    l'index de vitesse de guidage en queue de :GU#. La nouvelle valeur est
    prise en compte des l'impulsion :Mg suivante, sans etat a purger.
    Choix du 'g' minuscule : hors OnStep standard, ou la famille :R ne porte
    que les vitesses de slew (:RG/:RC/:RM/:RS/:Rn) et ne repond rien. Pas de
    collision avec ces commandes, et pas de risque de desynchronisation avec
    Ekos, qui n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
    [mega_monture.ino, teensy_monture.ino]
2026-07-26 App: aligne le parseur :GU# sur le nouveau format, corrige la detection
    - heure non reglee : '?' au lieu de 'F', suivant le changement firmware
    - detection OnStep reparee, deux bugs cumules qui la faisaient echouer a
    toute connexion sur monture a l'arret :
    * le test exigeait [Nn] puis [Pp] en positions 0 et 1. Suivi coupe, la
    chaine commence par "nNp" : f[1] valait 'N' et non 'p'. Le flag de
    parking est le seul toujours emis ('N' et 'n' sont tous deux absents
    pendant un GOTO en suivi), c'est lui qu'on teste maintenant.
    * le repli cherchait "on-step" dans le nom en minuscules, ce qui ne
    pouvait pas matcher "onstep" : :GVP# renvoie "OnStep", sans tiret.
    Consequence : is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
    [goto_andrivet.py]
2026-07-26 Retire fix2.py du suivi et ignore les scripts fix*.py
    Le fichier avait deja ete retire en f2d9696 puis re-ajoute par erreur en
    efd4193, un git add sur le dossier mega_monture le ratissant a chaque
    fois. Cause racine : .gitignore couvrait patch_*.py, test_*.py, sim_*.py
    et revert_*.py mais pas fix*.py, alors que la racine en contient plusieurs
    (fix2.py, fix_model.py, fix_pins.py) de meme nature jetable. Regle ajoutee
    pour que ca ne puisse plus se reproduire. Les fichiers restent sur disque.
2026-07-26 Bouchons pour :T1#/:T2#/:To#, supprime 2 s de gel dans Ekos
    Ces trois commandes ne recevaient aucune reponse. Contrairement a ce qu'on
    pourrait croire, l'interrupteur d'Ekos ne restait pas bloque : le driver
    teste !sendOnStepCommand(), et sendOnStepCommand() renvoie false aussi bien
    sur une reponse != '0' que sur un timeout. Le mode finissait donc par
    s'afficher comme actif, mais apres 2 s de gel et un warning "Timeout/Error
    on response. Check connection." qui faisait soupconner le cablage.
    - :T1#/:T2# repondent '1'. Le nombre d'axes suivis n'est pas selectionnable
    ici, il decoule de la geometrie (les deux en AltAz, l'axe horaire seul en
    fourche equatoriale) : acquitter est exact, il n'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
    [mega_monture.ino, teensy_monture.ino]
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2026-07-29 Fix EEPROM address overlap bug on 32-bit platforms for double types
    [teensy_monture.ino]
2026-07-29 Implement missing GET commands for configurator (GSp, GSm, GGa, GGe, GQa, GQz) and fix GS conflict
    [teensy_monture.ino]
2026-07-29 Fix GG command shadowing GGa and GGe
    [teensy_monture.ino]
2026-07-31 Ajout du support du Backlash dans le firmware et outil de mesure ZWO
    [measure_backlash_zwo.py, teensy_monture.ino]
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2026-07-31 Ajout du support du Backlash dans le firmware Arduino Mega
    [mega_monture.ino]
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2026-08-10 fix: move zwo tools out of collapsible astrometry panel
    [goto_andrivet_config_tool.py]
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2026-08-10 fix: Remove reset pointing model from autoguider
    [autoguide_spectro_zwo.py]
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2026-08-10 fix: Prevent ZWO timeout crash in preview mode when changing exposure
    [goto_andrivet_config_tool.py]
2026-08-10 fix: Stop and restart ZWO video stream when changing exposure to prevent 'Camera removed' crashes
    [goto_andrivet_config_tool.py]
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2026-09-03 Fix bugs issus de la revue de code (dérotateur, raquette virtuelle, backlash temps réel, etc.)
    [auto_model_zwo.py, goto_andrivet.py, mega_monture.ino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]
2026-09-03 Fix: reset inISR flag at the end of the ISR to prevent concurrent stepper bit-banging
    [mega_monture.ino, teensy_monture.ino]
2026-09-04 Fix bugs: Tkinter freeze on serial connection, read config domino effect, and math domain error in polar alignment
    [goto_andrivet_config_tool.py, polar_alignment_ui.py]
2026-09-05 Fix Az/Alt to RA/Dec inversion and Teensy raquette flash path
    [goto_andrivet.py, goto_andrivet_config_tool.py]
2026-09-05 Fix mechanical derotation issues: simulation, reversing, enabling via XDe, and firmware 360 wrap around
    [goto_andrivet.py, mega_monture.ino, teensy_monture.ino]
2026-09-09 Fix derotator rollover, correct Az to HA conversion, and update config tool UI labels for Teensy
    [goto_andrivet_config_tool.py]
2026-09-09 Fix installer source_dir for PyInstaller and add firmware folders
    [install_linux.py]
2026-09-09 Fix PyInstaller subprocess freezing due to invalid stdout and incorrect python executable
    [install_linux.py]
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2026-09-14 fix(pcb): inversion du sens du bornier 36V pour orienter les ouvertures des fils vers l exterieur gauche
    [monture.kicad_pcb, raquette.kicad_pcb]
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2026-09-20 Fix: modification des pins Teensy (FOCUS_EN sur 21, GPS sur Serial4)
    [teensy_monture.ino]
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2026-09-20 Fix: ajout effectif du composant PC SERIAL sur le PCB
    [monture.kicad_pcb]
2026-09-20 Doc: mise à jour pour le port série PC dédié et correction de sa position
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2026-09-20 PCB Raquette: Fix chevauchement (Teensy etait vertical a cause du SetOrientationDegrees90)
    [raquette.kicad_pcb]
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2026-09-20 PCB Raquette: Fix orientation des SolderPads (par defaut horizontal) et ajout de la serigraphie du pinout
    [raquette.kicad_pcb]
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2026-09-20 Auto-routing: tracé des pistes (avec classe Puissance 0.8mm pour la monture) et correction DRC
    [monture.kicad_pcb, raquette.kicad_pcb]
2026-09-20 Fix merge conflict in teensy_monture.ino
    [teensy_monture.ino]
2026-09-20 Fix raquette case height to match 150mm PCB and regenerate STLs
    [boitier_raquette.scad, boitier_raquette_base.stl, boitier_raquette_face_avant.stl]
2026-09-20 Fix inverted Y axis in raquette case holes (LCD and buttons)
    [boitier_raquette.scad, boitier_raquette_base.stl, boitier_raquette_face_avant.stl]
2026-09-20 Fix countersink depth for all closing screws
    [boitier_monture.scad, boitier_monture_couvercle.stl, boitier_raquette.scad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]
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2026-09-20 Separate PCB mounting standoffs from case closing pillars by increasing clearance
    [boitier_monture.scad, boitier_monture_base.stl, boitier_monture_couvercle.stl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]
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2026-09-29 Fix text sizes and thicknesses in monture PCB
    [monture.kicad_pcb]
2026-09-29 Fix annular ring on U_LM2596 pads
    [monture.kicad_pcb]
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2026-10-08 Correction mécanique PCB/boîtiers : chanfreins 45°, DRC KiCad 0 erreur, recalibrage OpenSCAD/FreeCAD et firmware
    [boitier_monture.scad, boitier_monture_assemblage.FCStd, boitier_monture_base.stl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]
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2026-10-11 README : ligne GPS Teensy corrigee et section materielle mise a jour
    - Tableau de cablage : sur Teensy 4.1, le TX du GPS va sur la broche 16
    (RX4) et son RX sur la broche 17 (TX4), comme le PCB et le firmware
    (Serial4). Les fils GPS sont donc croises entre Mega et Teensy.
    - Section "Mise a jour Materielle" : selecteur StepStick / driver externe
    5V par axe, orientation des modules, SPI non implemente (le reglage
    :XFS est sans effet, pas de case a cocher), jack 12V via D_JACK,
    pont VUSB-VIN a couper, convention RX/TX du port PC SERIAL.
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2026-10-12 Nettoyage : suppression des scripts jetables et patchs deja appliques
    - Scripts de modification ponctuelle : fix2.py, fix_model.py, fix_pins.py,
    enhance_rv_ui.py, enhance_teensy_ui.py
    - Tests et brouillons : test_model, test_model.cpp, autofocus_test.py,
    get_coords.py, old_teensy.ino
    - Patchs 0001/0002 du guidage non bloquant, deja appliques
    (54fc3a2, 084bee2)
    Aucun n'etait reference par les applis ni par les firmwares.
2026-10-12 TMC5160 en SPI1 : ponts SPI sur le PCB, configuration par le Teensy
    PCB monture :
    - 5 ponts a souder par support StepStick (broches 2..6 : SDI, SCK, CSN,
    SDO, CLK) vers le bus SPI1 du Teensy : MOSI 26, SCK 27, MISO 39,
    CS AZ/ALT/DEROT/FOCUS = 41/40/38/37 ; CLK vers GND. Ponts ouverts par
    defaut : A4988, DRV8825, TMC2209 fonctionnent comme avant.
    - Re-routage Freerouting : DRC 0 erreur, 0 non connecte, puissance en
    1,5 mm, buck inchange. build_kicad_pcbs.py aligne, rendus regeneres.
    Firmware Teensy :
    - Detection (IOIN) et configuration des BTT TMC5160 Pro : courant
    (Rsense 0,075), micro-pas, stealthChop ; reconfiguration au retour du
    36V (GSTAT.reset), etat 'E' sur defaut driver,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
2026-10-12 Boitier monture : hauteur portee a 45 mm pour les TMC5160
    - boitier_monture.scad : box_h 35 -> 45 mm ; base STL et rendu regeneres
    (le couvercle ne depend pas de box_h, STL inchange).
    - Assemblage FreeCAD : nouvelle base, couvercle remonte a Z 47,5, gabarits
    TMC5160 pire cas (15,3 x 20,4 x 23,2 mm sur le support) : 25,8 mm libres
    au-dessus de la carte du module, 4,2 mm de marge, aucune collision.
    - README : note de hauteur mise a jour.
2026-10-12 PCB monture : deux cartes, StepStick et drivers externes
    Carte StepStick (pcb/monture) :
    - Selecteur retire (SW_SEL, RN_SEL, 74HC126/74HCT125, pastilles EXT) :
    les supports sont pilotes directement par le Teensy ; rappels RN_EN
    (10k vers 3,3V) pour garder les drivers coupes au demarrage.
    - Ponts SPI TMC5160 conserves (decales de 0,1 mm : courtyards KiCad 10).
    - Re-routage Freerouting, buck manuel conserve : DRC 0 erreur, 0 non
    connecte. Assemblage FreeCAD : modele PCB reimporte, 0 collision.
    Carte drivers externes (pcb/monture_ext, nouvelle) :
    - Par axe : bornier J_VM (VM, GND) et bornier J_SIG (EN, STEP, DIR, GND)
    en 5 V via 3 x 74HCT125 ; 220 uF par sortie VM ; plans GND et +36V.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
2026-10-13 Firmwares monture : plage de l'axe AH/AZ et depart de rampe adouci
    - ForkEq : l'angle horaire d'axe reste dans ]-180, +180]. Avant, slewToAA
    prenait le plus court chemin sur currAz (replie 0..360) alors que azPos ne
    l'est jamais : une suite de GoTo passant par 12 h vrillait le passe-cable
    (2 tours dans le test) et pouvait faire passer le tube sous l'horizon
    (-16,6 deg) sans arret. Un axe laisse vrille (EEPROM) se deroule au GoTo
    suivant.
    - AltAz : plus court chemin, sauf au-dela de +/-270 deg du zero (AZ_WRAP_MAX).
    - GermanEq : inchange.
    - Sync (:CS, et :CM sur Mega) : azPos garde le representant le plus proche
    de la position reelle de l'axe, au lieu de currAz*PPD (0..360).
    - Dep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
2026-10-20 Raquette : menu Park, deparquage et position de parking reparees
    - Deparquer envoyait :hW#, inconnu des firmwares monture (reponse 0#) :
    la monture restait parquee, moteurs coupes. Envoie desormais :hR,
    comme goto_andrivet.py.
    - Definir position envoyait :SQa/:SQz, inconnus eux aussi : la position
    de parking n'etait jamais enregistree. Envoie desormais :BPa/:BPz,
    comme l'outil de configuration.
    - La raquette verifie la reponse et affiche IMPOSSIBLE (alarme monture
    ou pas de reponse) au lieu d'annoncer un succes dans tous les cas.
    README, carte StepStick : A4988 et DRV8825 demandent tous deux RESET
    relie a SLEEP sur le module (RESET du DRV8825 rappele au niveau bas en
    interne). Bro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
2026-10-20 Longitude LX200, mecanique lue a la connexion, compteurs de pas et focuseur
    Longitude (:Sg) : le firmware la lit en Ouest positif, comme LX200 et le
    driver INDI (siteLon = -val), mais les quatre clients envoyaient l'Est en
    positif. L'heure siderale etait calculee pour la longitude opposee (6,77 E
    devenait 6,77 W) : un GoTo sur Dubhe depuis Saint-Raphael arrivait a 19 deg
    en azimut. Corrige dans le configurateur (envoi et relecture de :Gg),
    goto_andrivet.py, raquette_virtuelle.py et la raquette physique (envoi ;
    sa lecture etait deja juste). Le firmware reste compatible Ekos.
    goto_andrivet.py : a la connexion, lit le type de monture, les rapports,
    les pas et les micro-pas (:GM, :GGa, :GGe, :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
2026-10-20 Carte du ciel : véracité, ergonomie et mise à jour en ligne
    Véracité (vérifiée contre SIMBAD et PyEphem) :
    - La carte était vue en miroir : face au Sud, l'Est apparaissait à droite,
    et les points cardinaux E/O avaient été inversés pour le masquer.
    Projection stéréographique corrigée (Est à gauche face au Sud, Nord en
    haut et Est à gauche en vue zénithale).
    - Précession IAU 1976 : catalogues J2000 ramenés à la date pour la carte
    et pour la monture (GoTo et sync envoient des coordonnées de la date,
    comme LX200/OnStep/INDI). Écart corrigé : 0,33° en médiane. Positions
    affichées en J2000.
    - Étoiles : 44 étoiles approximatives (Procyon décalée de 20,7°,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
2026-10-21 Carte du ciel : dérotateur intégré, focuseur intégré et focuseur ZWO EAF
    Dérotateur (onglet Dérotateur) : choix du type, intégré à la monture,
    ZWO CAA (USB), série (SETPOS) ou simulation. L'intégré passe par la
    connexion de la monture : pas par degré envoyés (:XDp), axe activé
    (:XDe1), angles par :XDa (compensation de la rotation de champ et
    contrôle manuel). Avant, il dépendait d'un réglage du configurateur que
    la carte ne lisait pas, et les pas par degré n'étaient jamais envoyés.
    Le firmware ne l'anime qu'en AltAz : rappelé sous le choix.
    Focuseur (nouvel onglet) : intégré à la monture (:XFe1, :XF+/:XF-/:XFQ,
    vitesses :XFs/:XFf) ou ZWO EAF (SDK). Boutons à maint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
